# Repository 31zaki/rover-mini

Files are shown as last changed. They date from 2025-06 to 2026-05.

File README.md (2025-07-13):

# rover mini
Welcome to rover-mini Repository!!

This is a self-initiated project designed to explore and learn the full spectrum of engineering from mechanical design and electronics to embedded systems and software development.

<details>
<summary><strong>NOTE for Reviewers and Users</strong></summary>

While I have experience developing hardware as part of a [student-led Mars rover team](https://www.instagram.com/ares_project_official/),
my academic background is originally in Biomedical Engineering.
Fields like robotics, software development, and PCB design are still outside my core expertise.
This project is part of my personal learning journey, and I’m fully aware that there may — or probably should — be mistakes or imperfections.
Any feedback or advice would be warmly appreciated.

Thank you!

</details>

## philosophy
**tiny, but mighty**
  - High performance in not enough; a heart must be woven into the design.
  - More than size — like "山椒は小粒でもぴりりと辛い"
  - Designed with Japanese craftsmanship — tiny in size, vast in spirit.

## features
**manual control**
  - Responsive remote operation using a PlayStation controller via Xbee and Bluetooth communication.
  - Essential for field testing and fine-tuning — offering an intuitive and playful driving experience.

**autonomous**
  - Core functionality designed for the University Rover Challenge Autonomous Mission.
  - Capable of navigating to specified GPS coordinates, detecting ARUCO markers, and identifying mission targets like bottles and hammers.
  - Striving toward true autonomy — small but strategic.

**collaboration with the main rover**
  - Built for intelligent mission sharing: coordinate with the main rover to divide tasks and maximize mission points.
  - Share positional and target information to enhance team efficiency and achieve greater success together.

## hardware overview

This mini rover is designed to be compact yet powerful, with a strong focus on functional performance, manufacturability, and aesthetic design.

{AB2F8BDA-105C-4608-8CE0-41E401231829}

### key features:
- High-torque 4WD system capable of navigating tough terrains.
- Rocker mechanism designed with compact miter gears, providing superior maneuverability and articulation.
- Simple and robust fabrication, combining 3D printed parts and laser-cut acrylic plates.
- Two-layer acrylic structure to enhance overall strength and rigidity.
- RealSense depth camera integrated for obstacle avoidance and spatial awareness, supporting advanced path planning.
- Design with a skeleton-like aesthetic, exposing parts of the structure for a visually engaging appearance.
- Soft rubber tyres for excellent traction and smooth handling across various surfaces.
- Dual-computer architecture:
  - Jetson Nano handles computationally intensive tasks like vision processing.
  - Raspberry Pi Pico 2W manages low-level motion control.

### specifications:
- Dimensions: 330 mm (W) × 370 mm (L) × 400 mm (H)
- Weight: 5 kg
- Maximum Speed: 10 m/s
- Power Source: Two 7.2V 4000mAh Ni-MH batteries
- 4-wheel drive system with custom 3D printed inner wheels and rubber tyres

## directory structure (今のところ)
```
```

## system components

| **category** | **component** | **qty** | **details** |
|---|---|---|---|
| **hardware** | Main Computer | 1 | [Jetson Nano 4GB](https://developer.nvidia.com/embedded/learn/get-started-jetson-nano-devkit)|
| | Sub Computer | 1 | [Raspberry Pi Pico 2 W](https://akizukidenshi.com/catalog/g/g130330/)|
| | Battery | 2 | [7.2V 4000mAh Ni-MH for Tamiya RC](https://www.amazon.co.jp/-/en/dp/B07789SDYY/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) |
| | Drive Motor | 4 | [100:1 Metal Gearmotor 37Dx73L mm 12V with 64 CPR Encoder (Helical Pinion)](https://www.pololu.com/product/5167) |
| | Motor Driver | 4 | [TB67H450FNG](https://akizukidenshi.com/catalog/g/g114967/) |
| | Tyre | 4 | [5.1 inch RC Crawler Tyre](https://www.amazon.co.jp/dp/B0D9VZH5C3?ref=ppx_yo2ov_dt_b_fed_asin_title)|
| | IMU (Inertial Measurement Unit) | 1 |[BNO055](https://akizukidenshi.com/catalog/g/g116996/) |
| | Camera | 1 |[Realsense 435i](https://www.intelrealsense.com/depth-camera-d435i/) |
| | Indicator | 1 |[LED (RGB)](https://www.amazon.co.jp/dp/B09L82BP77?ref=ppx_yo2ov_dt_b_fed_asin_title&th=1) |
| | Communication Module | 2 |[Xbee](https://www.digi.com/resources/documentation/digidocs/pdfs/90002173.pdf) |
| | GPS Module | 1 |[Gravity GPS](https://wiki.dfrobot.com/SKU_TEL0157_Gravity_GNSS_Positioning_Module) |
| | Emergency Stop Button | 1 |[KILIGEN 22mm 12-220V 5A](https://www.amazon.co.jp/dp/B0956SRHKC?ref=ppx_yo2ov_dt_b_fed_asin_title&th=1) |
| | Miter gear for Rocker Mechanism | 4 |[M1S25*2310](https://jp.misumi-ec.com/vona2/detail/221000021851/?ProductCode=M1S25*2310)|
| | Bearings for Rocker Mechanism | 6 |[SFL6700ZZ](https://jp.misumi-ec.com/vona2/detail/110302273720/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)|
| | Rocker Shaft Holder | 2 |[SSTHIC10M](https://jp.misumi-ec.com/vona2/detail/110300011320/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)|
| | Wheel Shaft Hub | 2 |[AO-8038](https://tamiyashop.jp/shop/g/g89877/)|
| **software** | Operating System || Ubuntu 22.04 |
| | Programming Framework || ROS 2 Humble |
| | Control Algorithm || TBD |
| | Communication Protocol || Wireless communication with the main rover (Xbee) |
| **electronics** | Please refer to `/Electronics/BOM/`  |||

## Jetson Nano GPIO configuration

| **GPIO pin number**  | **device name** | **connection (pin or function)**  | **purpose** |
|---:|---|---|---|
| 3 (I2C SDA) | I2C Bus | SDA | I2C Data for GPS/BNO055 |
| 5 (I2C SCL) | I2C Bus | SCL | I2C Clock for GPS/BNO055 |
| 7 | LED1 | LED_1 | Indicator LED1 Control |
| 11 | LED2 | LED_2 | Indicator LED2 Control |
| 13 | LED3 | LED_3 | Indicator LED3 Control |
| 8 (UART TX) | Pico RX | JETSON_TX-PICO_RX | UART Communication |
| 10 (UART RX) | Pico TX | JETSON_RX-PICO_TX | UART Communication |

## Raspberry Pi pico GPIO configration
| **GPIO pin number** | **device name** | **connection (pin or function)**  | **purpose** |
|---:|---|---|---|
| GP0 | Jetson Nano UART | JETSON_RX-PICO_TX | UART Communication |
| GP1 | Jetson Nano UART | JETSON_TX-PICO_RX | UART Communication |
| GP2 | Motor Driver LF | LF_IN1 | Motor control input |
| GP3 | Motor Driver LF | LF_IN2 | Motor control input |
| GP4 | Motor Driver RF | RF_IN1 | Motor control input |
| GP5 | Motor Driver RF | RF_IN2 | Motor control input |
| GP6 | Motor Driver LF | LF_ENCODER_A | Encoder reading |
| GP7 | Motor Driver LF | LF_ENCODER_B | Encoder reading |
| GP8 | Motor Driver RF | RF_ENCODER_A | Encoder reading |
| GP9 | Motor Driver RF | RF_ENCODER_B | Encoder reading |
| GP10 | Motor Driver LR | LR_IN1 | Motor control input |
| GP11 | Motor Driver LR | LR_IN2 | Motor control input |
| GP12 | Motor Driver LR | LR_ENCODER_A | Encoder reading |
| GP13 | Motor Driver LR | LR_ENCODER_B | Encoder reading |
| GP14 | Motor Driver RR | RR_IN1 | Motor control input |
| GP15 | Motor Driver RR | RR_IN2 | Motor control input |
| GP16 | Motor Driver RR | RR_ENCODER_A | Encoder reading |
| GP17 | Motor Driver RR | RR_ENCODER_B | Encoder reading |

LF: Left Front<br>
RF: Right Front<br>
LR: Left Rear<br>
RR: Right Rear<br>

## install required python libraries

## miscellaneous

### project name
The project name "rover-mini" is inspired by the iconic British car [Mini](https://en.wikipedia.org/wiki/Mini). Like its namesake, this rover aims to be compact, functional, and adorable.

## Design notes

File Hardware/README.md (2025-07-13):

# Mechanical Design – `hardware/`

This directory contains the mechanical design files for the rover-mini project.
It includes 3D models, structural notes, and mechanical features essential for the rover's operation.



## Overview

The mechanical frame of the rover is designed to be **compact, lightweight, and structurally robust**.

- **Dimensions**: 330 mm (W) × 370 mm (L) × 400 mm (H)
- **Weight**: Approx. 5.0 kg
- The chassis is constructed using **laser-cut acrylic plates**, arranged in a **two-layer structure** to improve strength and rigidity.
- The design focuses on **maintainability** and **fabrication simplicity**, with minimal part count and tool requirements.

## CAD Files

All CAD models are located under `hardware/cad/`.

- Formats: `.f3d`, `f3z` (for Autodesk Fusion) and `.step` (for general 3DCAD)
- The entire assembly is included.
- Feel free to download, explore, and modify the design as you wish!

## 3D Printed Parts

All components that require 3D printing are stored in the `3D_Print/` subdirectory.

- Key parts include: wheel hubs, rocker gearboxes, motor mounts, and structural connectors
- Files are provided in `.stl` format and optimised for standard FDM printers
- Recommended materials:
  - **PLA**: inexpensive and easy to print
  - **ABS**: better thermal resistance and strength, but more difficult to print

> ⚠️ Please check printer tolerances carefully — especially for mated or interlocking parts like gear housings.

## Laser-Cut Parts

All parts designed for laser cutting are stored in the `Laser_Cut/` subdirectory.

- These parts are primarily used for the rover's structural frame (e.g., chassis plates, mounting brackets).
- Files are provided in formats such as `.dxf` or `.svg`, suitable for most laser cutting software.
- Material recommendation: **5 mm acrylic** for base plate and top plate, **2 mm acrylic** for gearbox bottom window plate

> ⚠️ Double-check your laser cutter's bed size and kerf settings before cutting.
> Some mounting holes or slots may require slight tuning depending on the material and cutter precision.

## Rocker Mechanism with Compact Miter Gearbox

The rover features a **rocker-style suspension system**, enhancing manoeuvrability and adaptability on rough terrain.

- A **custom-built gearbox with compact miter gears** connects the left and right rocker arms
- This design enables smooth, passive articulation and synchronised movement across uneven surfaces
- **Miter gears** were chosen for their **1:1 ratio** and ability to **redirect rotational motion by 90°**, making them ideal for space-limited assemblies
- The gearbox casing is 3D printed and positioned centrally within the chassis for optimal balance and accessibility

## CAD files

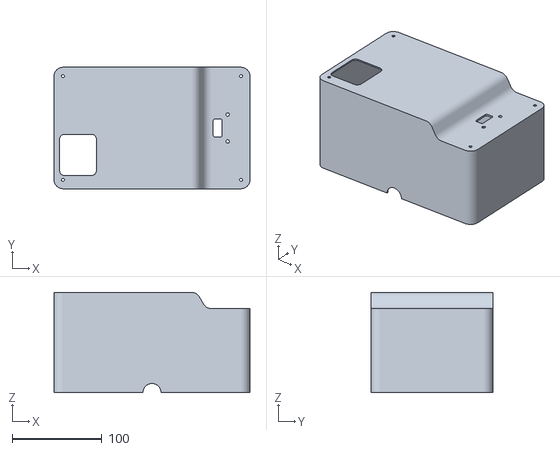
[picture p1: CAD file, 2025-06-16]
Hardware/3d_print/Chassis/Hood.stl
218.5 x 135.5 x 111.5

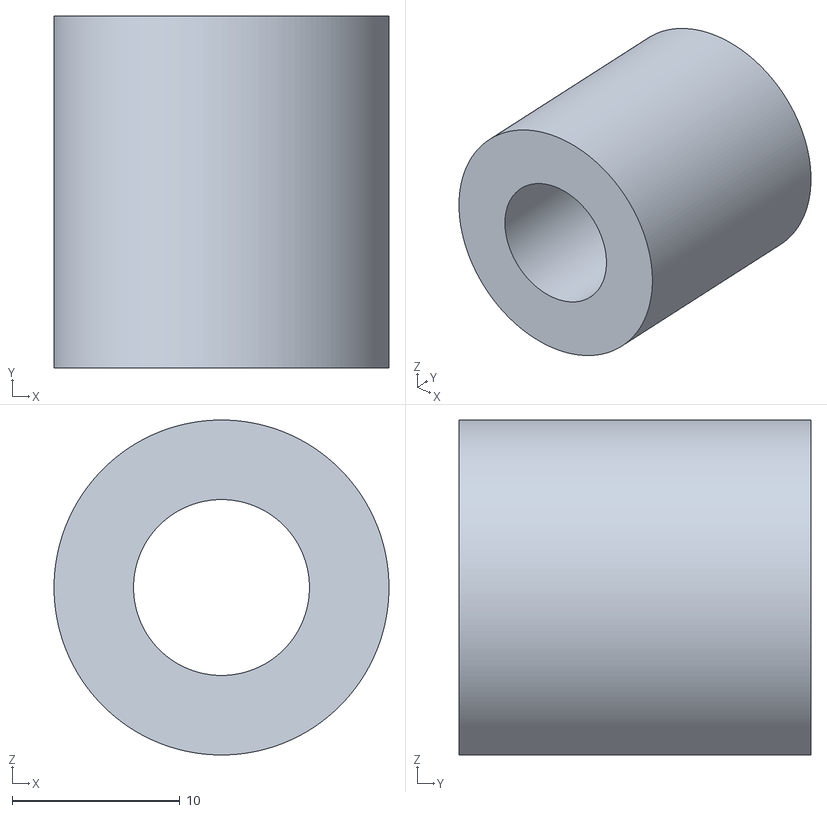
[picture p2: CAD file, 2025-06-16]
Hardware/3d_print/Gearbox/Chassis_Spacer_R.stl
20.0 x 21.0 x 20.0

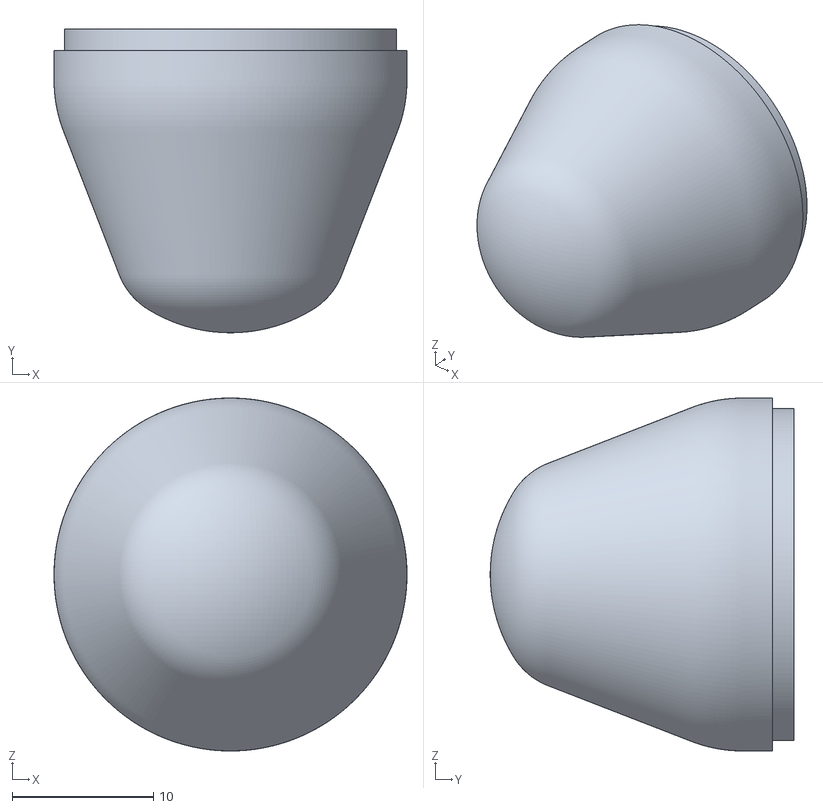
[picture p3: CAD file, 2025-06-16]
Hardware/3d_print/Indicator_Lamp/Lamp.stl
25.0 x 21.5 x 25.0

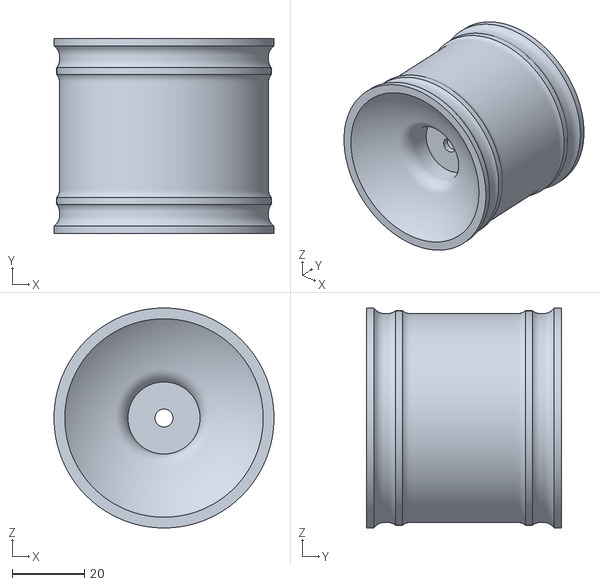
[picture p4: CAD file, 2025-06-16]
Hardware/3d_print/Tyre/Wheel_design_4_LR.stl
61.0 x 54.0 x 61.0

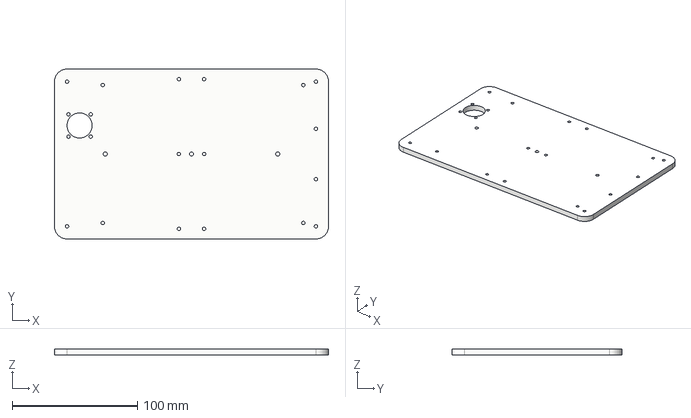
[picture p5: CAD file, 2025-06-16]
Hardware/laser_cutter/Base_Plate.step
218.5 x 135.5 x 5.00 mm

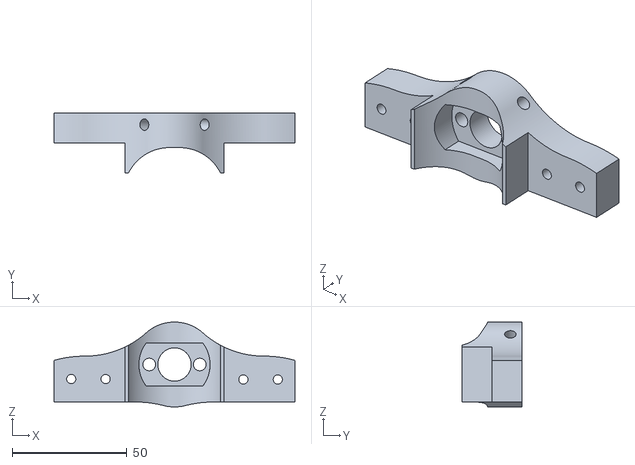
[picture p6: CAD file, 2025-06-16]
Hardware/3d_print/Chassis/Rocker_Hub_L.stl
105.0 x 26.0 x 37.0

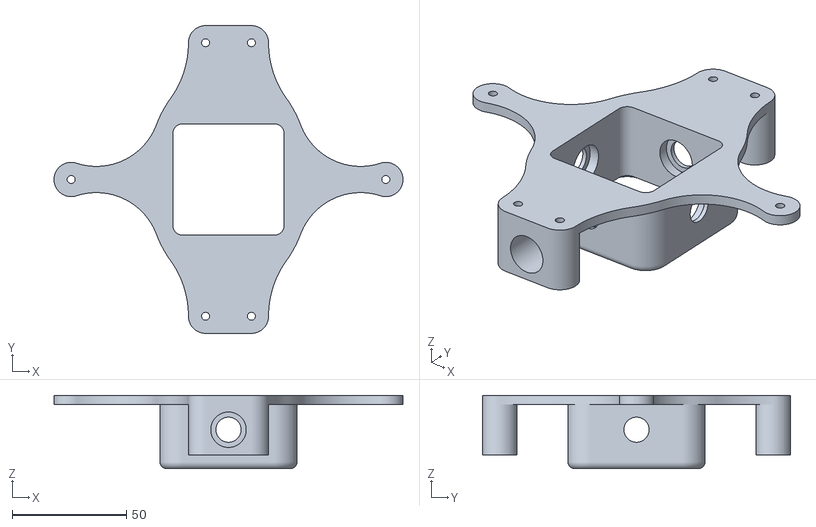
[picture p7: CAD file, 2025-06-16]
Hardware/3d_print/Gearbox/Gearbox_Cover.stl
152.5 x 134.5 x 32.0

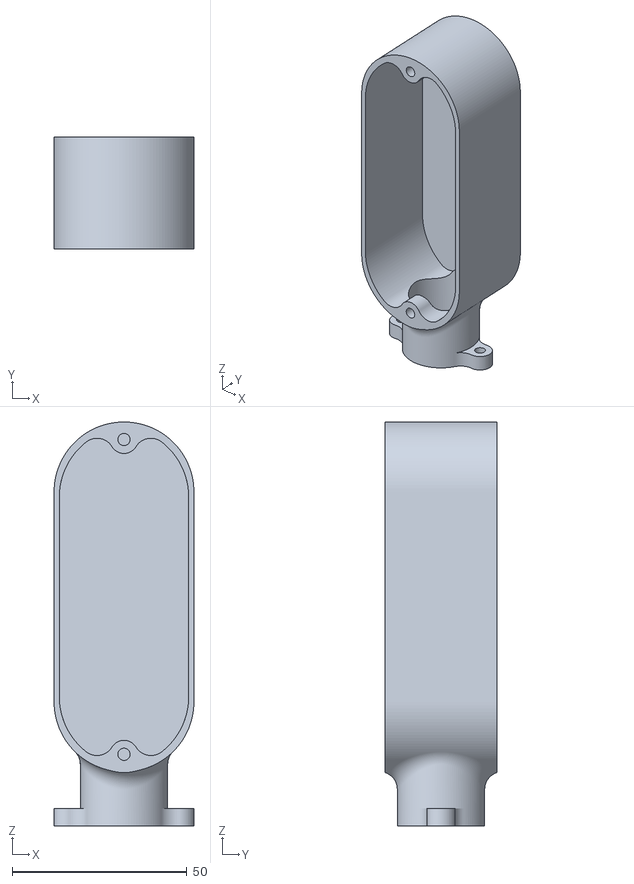
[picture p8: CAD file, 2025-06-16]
Hardware/3d_print/Indicator_Lamp/Lamp_Box.stl
40.0 x 32.0 x 115.5

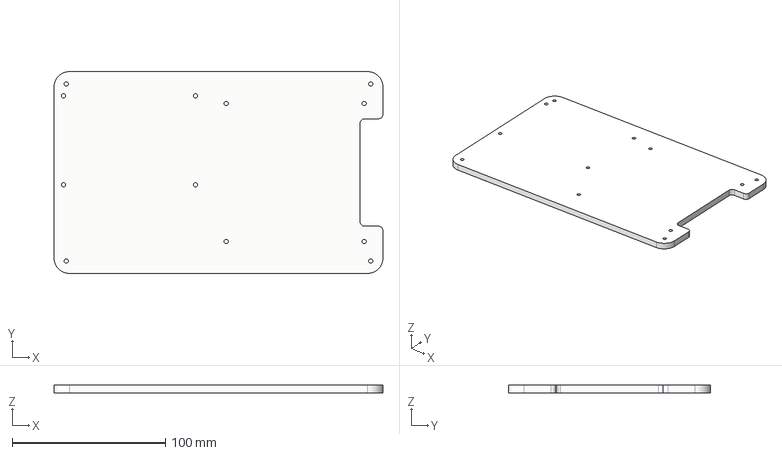
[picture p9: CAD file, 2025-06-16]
Hardware/laser_cutter/Top_Plate.step
214.5 x 131.5 x 5.00 mm

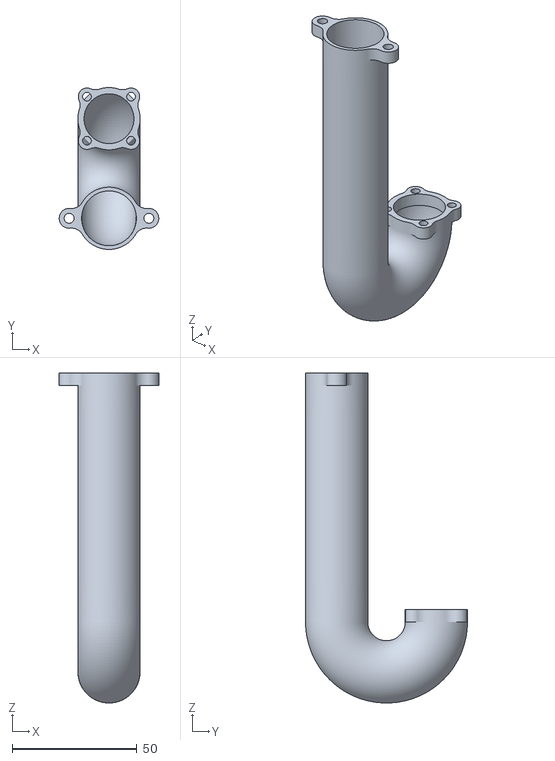
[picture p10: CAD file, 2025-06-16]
Hardware/3d_print/Indicator_Lamp/Tube_1.stl
40.0 x 65.0 x 132.5

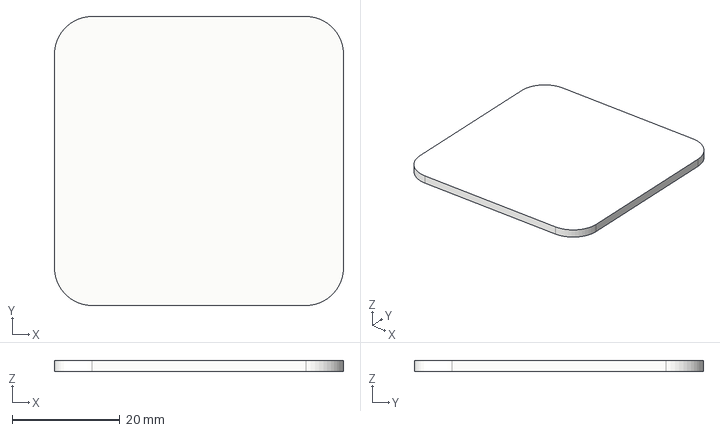
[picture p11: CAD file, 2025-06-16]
Hardware/laser_cutter/Gearbox_Window.step
53.7 x 53.7 x 2.00 mm

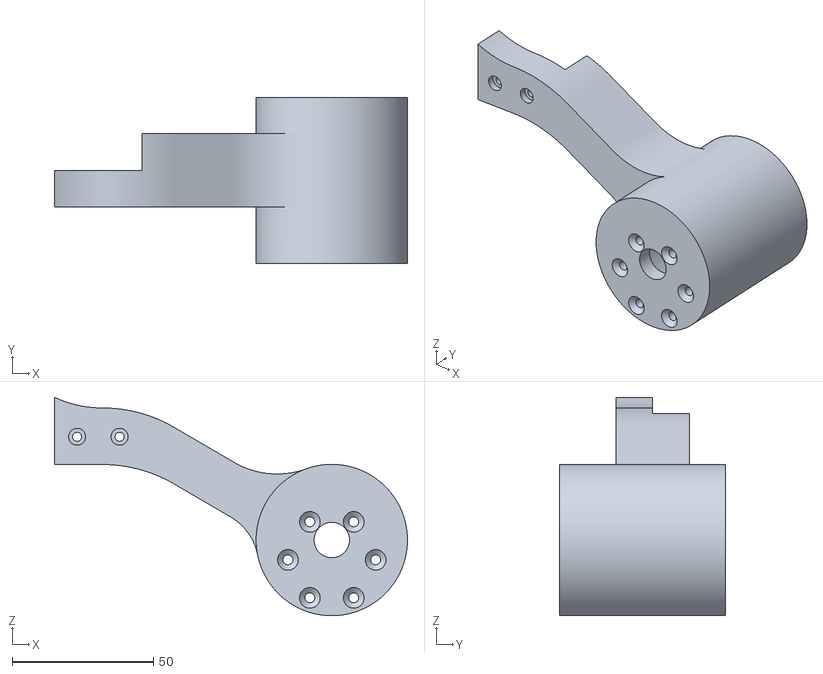
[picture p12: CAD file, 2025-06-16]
Hardware/3d_print/Chassis/Motor_Mount_RF.stl
124.8 x 58.7 x 77.2

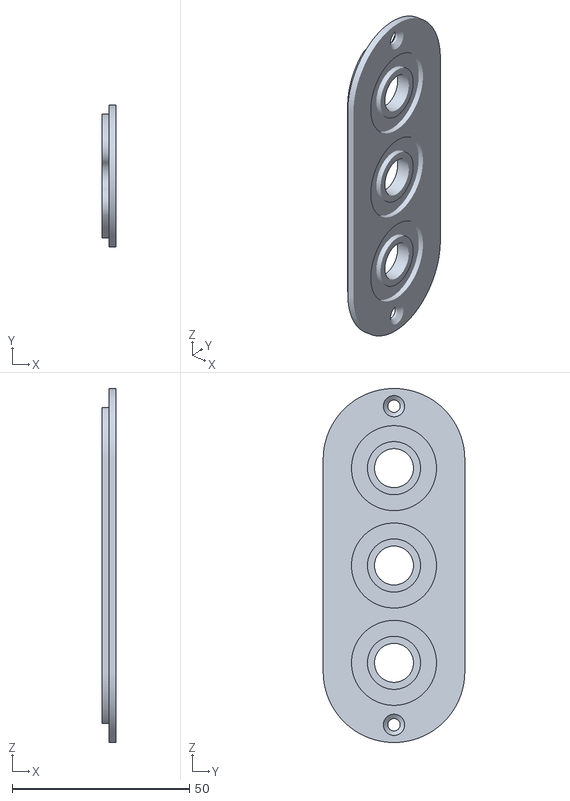
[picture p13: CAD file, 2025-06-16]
Hardware/3d_print/Indicator_Lamp/Lamp_Mount.stl
4.00 x 40.0 x 100.0

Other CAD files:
Electronics/main_board.f3z
Hardware/3d_print/Chassis/Battery_Holder.stl
Hardware/3d_print/Chassis/ESB_Mount.stl
Hardware/3d_print/Chassis/Motor_Mount_LF.stl
Hardware/3d_print/Chassis/Motor_Mount_RR.stl
Hardware/3d_print/Chassis/Neck.stl
Hardware/3d_print/Chassis/Stand-off_50.5mm.stl
Hardware/3d_print/Chassis/Stand-off_69mm.stl
Hardware/laser_cutter/Base_Plate.dxf
Hardware/laser_cutter/Gearbox_Window.dxf
Hardware/laser_cutter/Top_Plate.dxf

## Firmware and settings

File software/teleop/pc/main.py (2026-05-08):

"""
rover-mini teleop PC-side entry point.

Flow:
  PS Controller (Bluetooth)
        ↓  pygame
  controller.py  →  RoverCommand
        ↓
  packet.py      →  5-byte binary packet
        ↓
  xbee_sender.py →  XBee serial  ~~~wireless~~~>  Jetson Nano
"""

import sys
import time
import argparse

from controller  import ControllerReader
from xbee_sender import XBeeSender, list_ports
from packet      import ButtonFlag


# ── Defaults ─────────────────────────────────────────────────────────────────
DEFAULT_PORT     = "/dev/ttyUSB0"   # change to COMx on Windows
DEFAULT_BAUDRATE = 9600
SEND_RATE_HZ     = 20               # packets per second
# ─────────────────────────────────────────────────────────────────────────────


def parse_args() -> argparse.Namespace:
    parser = argparse.ArgumentParser(description="rover-mini PC teleop")
    parser.add_argument("--port",     "-p", default=DEFAULT_PORT,
                        help=f"XBee serial port (default: {DEFAULT_PORT})")
    parser.add_argument("--baudrate", "-b", default=DEFAULT_BAUDRATE, type=int,
                        help=f"Baud rate (default: {DEFAULT_BAUDRATE})")
    parser.add_argument("--hz",             default=SEND_RATE_HZ, type=int,
                        help=f"Send rate in Hz (default: {SEND_RATE_HZ})")
    parser.add_argument("--list-ports",     action="store_true",
                        help="List available serial ports and exit")
    parser.add_argument("--dry-run",        action="store_true",
                        help="Run without XBee (print packets to stdout only)")
    return parser.parse_args()


def main():
    args = parse_args()

    # ── List ports and exit ───────────────────────────────────────────────
    if args.list_ports:
        ports = list_ports()
        print("Available serial ports:")
        for p in ports:
            print(f"  {p}")
        sys.exit(0)

    # ── Init controller ───────────────────────────────────────────────────
    try:
        ctrl = ControllerReader()
    except RuntimeError as e:
        print(f"[Error] {e}")
        sys.exit(1)

    # ── Init XBee sender ──────────────────────────────────────────────────
    sender = None
    if not args.dry_run:
        try:
            sender = XBeeSender(args.port, args.baudrate)
        except RuntimeError as e:
            print(f"[Error] {e}")
            ctrl.close()
            sys.exit(1)
    else:
        print("[DryRun] XBee not connected. Printing packets to stdout.")

    # ── Main loop ─────────────────────────────────────────────────────────
    interval = 1.0 / args.hz
    print(f"\n[Teleop] Running at {args.hz} Hz. Press OPTIONS to emergency-stop. Ctrl-C to quit.\n")

    try:
        while True:
            t_start = time.monotonic()

            cmd = ctrl.read()

            # QUIT event from pygame
            if cmd is None:
                print("\n[Teleop] Quit event received.")
                break

            # Emergency stop: print warning
            if ButtonFlag.EMERGENCY_STOP in cmd.buttons:
                print("[!!] EMERGENCY STOP")

            # Send
            if sender:
                sender.send(cmd)
            else:
                # dry-run: print encoded bytes + human-readable
                raw = cmd.encode()
                print(f"{str(cmd)}  |  {raw.hex(' ').upper()}")

            # Rate limiter
            elapsed = time.monotonic() - t_start
            sleep_time = interval - elapsed
            if sleep_time > 0:
                time.sleep(sleep_time)

    except KeyboardInterrupt:
        print("\n[Teleop] Interrupted.")

    finally:
        print(f"\n[Stats] {sender.stats if sender else 'dry-run'}")
        if sender:
            sender.close()
        ctrl.close()


if __name__ == "__main__":
    main()

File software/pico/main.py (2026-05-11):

from drive_pid import DrivePID
from machine import UART, Pin, PWM
import struct
import time

# 起動時LED点滅
led = Pin("LED", Pin.OUT)
for i in range(5):
    led.on()
    time.sleep(0.1)
    led.off()
    time.sleep(0.1)

PACKET_HEADER = 0xFE
PACKET_SIZE   = 5

drive = DrivePID()
uart  = UART(0, baudrate=9600, tx=Pin(0), rx=Pin(1))

def decode(data):
    if len(data) != PACKET_SIZE or data[0] != PACKET_HEADER:
        return None
    _, v_u, w_u, flags, checksum = struct.unpack("BBBBB", data)
    if (v_u ^ w_u ^ flags) != checksum:
        return None
    v = (v_u if v_u < 128 else v_u - 256)
    w = (w_u if w_u < 128 else w_u - 256)
    return v, w, flags

buf = b""
last_packet_time = time.ticks_ms()
WATCHDOG_MS = 500  # 500ms以内にパケットが来なければ停止

print("Pico PID ready.")

while True:
    # UART受信
    if uart.any():
        buf += uart.read()
        last_packet_time = time.ticks_ms()

        while len(buf) >= PACKET_SIZE:
            if buf[0] != PACKET_HEADER:
                buf = buf[1:]
                continue

            packet = buf[:PACKET_SIZE]
            buf    = buf[PACKET_SIZE:]

            result = decode(packet)
            if result:
                v, w, flags = result
                if flags & 0x10:  # EMERGENCY_STOP
                    drive.stop()
                    print("EMERGENCY STOP")
                else:
                    drive.set_velocity(v, w)
            else:
                print("checksum error")

    # ウォッチドッグ：パケットが途絶えたら停止
    if time.ticks_diff(time.ticks_ms(), last_packet_time) > WATCHDOG_MS:
        drive.stop()

    # PID更新
    drive.update()

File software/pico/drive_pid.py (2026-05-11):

from motor_pid import MotorPID

MAX_RPM = 100  # 最大目標RPM

class DrivePID:
    def __init__(self):
        self.rf = MotorPID(pin1=4,  pin2=5,  enc_a=8)
        self.rr = MotorPID(pin1=14, pin2=15, enc_a=16)
        self.lf = MotorPID(pin1=3,  pin2=2,  enc_a=6)
        self.lr = MotorPID(pin1=11, pin2=10, enc_a=12)

    def set_velocity(self, v, w):
        # v, w: -100 ~ +100
        left  = v - w
        right = v + w

        # 正規化
        scale = max(abs(left), abs(right), 100) / 100
        left  /= scale
        right /= scale

        # RPMに変換
        left_rpm  = left  / 100 * MAX_RPM
        right_rpm = right / 100 * MAX_RPM

        self.lf.set_target_rpm(left_rpm)
        self.lr.set_target_rpm(left_rpm)
        self.rf.set_target_rpm(right_rpm)
        self.rr.set_target_rpm(right_rpm)

    def update(self):
        self.lf.update()
        self.lr.update()
        self.rf.update()
        self.rr.update()

    def stop(self):
        self.lf.stop()
        self.lr.stop()
        self.rf.stop()
        self.rr.stop()

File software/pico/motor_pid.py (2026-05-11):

from machine import Pin, PWM
from time import ticks_ms, ticks_diff

COUNTS_PER_REV = 1600
MAX_VOLTAGE    = 12.0
BATT_VOLTAGE   = 8.0
MAX_DUTY       = int(BATT_VOLTAGE / MAX_VOLTAGE * 65535)  # ≈ 43690

class MotorPID:
    def __init__(self, pin1, pin2, enc_a,
                 kp=2.0, ki=3.0, kd=0.01):
        # モーター
        self.in1 = PWM(Pin(pin1))
        self.in2 = PWM(Pin(pin2))
        self.in1.freq(1000)
        self.in2.freq(1000)

        # エンコーダー
        self.enc_a = Pin(enc_a, Pin.IN, Pin.PULL_UP)
        self.count = 0
        self._direction = 1
        self.enc_a.irq(trigger=Pin.IRQ_RISING,
                       handler=self._encoder_cb)

        # PID
        self.kp = kp
        self.ki = ki
        self.kd = kd
        self.target_rpm  = 0.0
        self._integral   = 0.0
        self._prev_error = 0.0
        self._prev_count = 0
        self._prev_time  = ticks_ms()

    def _encoder_cb(self, pin):
        self.count += self._direction

    def set_target_rpm(self, rpm):
        self.target_rpm = rpm
        self._integral  = 0.0
        if rpm >= 0:
            self._direction = 1
        else:
            self._direction = -1

    def _set_pwm(self, power):
        power = max(-100, min(100, power))
        duty  = int(abs(power) / 100 * MAX_DUTY)
        if power > 0:
            self.in1.duty_u16(duty)
            self.in2.duty_u16(0)
        elif power < 0:
            self.in1.duty_u16(0)
            self.in2.duty_u16(duty)
        else:
            self.in1.duty_u16(0)
            self.in2.duty_u16(0)

    def update(self):
        now = ticks_ms()
        dt  = ticks_diff(now, self._prev_time) / 1000.0
        if dt < 0.01:
            return

        delta      = self.count - self._prev_count
        actual_rpm = (delta / COUNTS_PER_REV) * 60.0 / dt

        error          = self.target_rpm - actual_rpm
        self._integral += error * dt
        # windup防止
        self._integral = max(-100, min(100, self._integral))
        derivative     = (error - self._prev_error) / dt

        output = (self.kp * error +
                  self.ki * self._integral +
                  self.kd * derivative)

        self._set_pwm(output)

        self._prev_error = error
        self._prev_count = self.count
        self._prev_time  = now

    def stop(self):
        self.target_rpm  = 0.0
        self._integral   = 0.0
        self._set_pwm(0)

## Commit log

2025-06-16 upload 3d models in /hardware
    [Base_Plate.dxf, Base_Plate.step, Battery_Holder.stl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]
2025-07-13 add electronics
    [main_board.f3z]
2026-05-08 fix: change baudrate to 9600 for XBee S2C
    [main.py, xbee_sender.py]
2026-05-08 fix: rename Software to software (case sensitive)
    [controller.py, debug_controller.py, main.py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]
2026-05-08 feat: add common packet and jetson receiver node
2026-05-11 feat: Add pico firmware
